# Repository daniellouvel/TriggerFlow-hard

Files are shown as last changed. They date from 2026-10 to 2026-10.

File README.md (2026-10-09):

# TriggerFlow — Architecture matérielle

> **Branche `v2-wroom`** : version 2, la DevKit est remplacée par le module ESP32-S3-WROOM-1-N16R8 soudé sur la carte (mêmes GPIO, firmware inchangé). Voir [docs/mcu-v2-wroom.md](docs/mcu-v2-wroom.md). La v1 (DevKit) est sur `main` et l'étiquette `v1.0`.

Boîtier de déclenchement généraliste pour photographie haute vitesse : détection multi-capteurs, moteur de règles programmable, pilotage de sorties variées (flash, électrovannes, appareil photo, servo, relais) et d'appareils secteur via des prises Wi-Fi.

Contrôlable par **USB (PC)** et **Wi-Fi/BLE (application mobile)**.

Statut (05/10/2026) : **schéma complet et validé** dans EasyEDA (Blocs 1, 2, 3, 5, 5b, 8, 10, 12 servo, 13 relais et feuille ESP32) : netlist vérifiée net par net, ERC 0 erreur / 0 avertissement ; référence : `netlist/Netlist_Schematic1_2026-10-05.tel`. Moteur pas à pas, PWM lumière/servo et relais ×3 supprimés (prises Wi-Fi). Module capteur universel conçu (8 variantes). Implantation PCB v4 (175 × 125 mm, 4 couches) recalée sur la netlist de référence. Firmware non commencé.

---

## 1. Plateforme

- **MCU** : module ESP32-S3-WROOM-1-**N16R8** soudé sur la carte (16 Mo flash Quad, 8 Mo PSRAM Octal) ; en v1, le même module sur une DevKitC-1
- **Cœurs** : dual-core Xtensa LX7, 240 MHz
- **Connectivité native** : Wi-Fi 2.4 GHz, Bluetooth LE, USB natif (device)
- v2 : **1 port USB-C** sur l'USB natif (GPIO 19/20) → programmation (USB-Serial/JTAG) et **contrôle PC** ; console série UART0 (GPIO 43/44) sur pastilles de test la barrette U103 (GND, TX, RX)
- v1 : la DevKit avait 2 ports USB-C (pont série et USB natif)

## 2. Cahier des charges fonctionnel

| Paramètre | Valeur retenue |
|---|---|
| Canaux d'entrée (capteurs) | 6, génériques et reconfigurables (gain + seuil logiciels) |
| Types de capteurs supportés | Son, laser/optique, piézo, contact sec — adaptables via un front-end universel |
| Utilisation des entrées | Rarement simultanées ; les 6 canaux existent surtout pour la flexibilité de branchement, pas pour du traitement massivement parallèle en continu |
| Logique inter-canaux | Moteur de règles programmable (ET / OU / conditions avancées), pas de simple mapping 1:1 figé |
| Précision de déclenchement | ±10 µs ou mieux |
| Plage de délai programmable | De la µs à plusieurs secondes, résolution constante |
| Alimentation | Secteur (pas de contrainte de consommation) |
| Pilotage | USB (PC), Wi-Fi (page web servie par le boîtier et/ou app mobile), Bluetooth LE (contrôle de proximité / mode secours) |
| Affichage local | Aucun (tout passe par l'app / le logiciel PC) |

## 3. Sorties

| Sortie | Quantité | Indépendance | Étage de puissance |
|---|---|---|---|
| Flash (pulse simple) | 4 | Délai indépendant par canal | Opto HCPL-063L + inverseur 74LVC2G04 + 2N7002, côté isolé (VISO) |
| Déclenchement appareil photo | 1 prise, **focus + shutter séparés** (2 contacts) | Timing indépendant | Idem flash (isolé) |
| Électrovanne | 6 | Durée de pulse indépendante par canal | AO3400A + diode de roue libre SS14, PTC 1,1 A |
| Servo | 1 | Non critique (LEDC 50 Hz) | Rail 6 V / 3 A dédié (LM2596S-ADJ depuis le 12 V, coupable), signal par buffer 74AHCT1G125 5 V |
| Relais (contact sec) | 1 | Non critique (MCP23017) | HF32F/012-ZS3, 1RT 3 A / 30 V DC, basse tension uniquement |
| **Prises Wi-Fi (secteur)** | illimité | Non critique (50–500 ms) | Prises connectées commandées en local (HTTP/MQTT) — voir section 3.1 |

**Total sur la carte : 14 sorties** (4 flash + 2 caméra + 6 vannes + servo + relais). Supprimés : moteur pas à pas (Bloc 4), PWM lumière/servo (Bloc 7), relais ×3 sur RJ45 (Bloc 6). Une **lumière 12 V dimmable** se branche sur une sortie vanne libre (même étage MOSFET, PWM ≈ 20 kHz par le firmware, 1,1 A max) : rien à ajouter côté matériel.

### 3.1 Sorties Wi-Fi (remplacent les relais)

Les appareils secteur sans contrainte de timing (éclairage, petit compresseur, ventilateur, pompe…) sont pilotés par des **prises connectées Wi-Fi** commandées par l'ESP32 sur **son propre réseau** (point d'accès SoftAP avec DHCP : sans box, utilisable partout) :
- prises recommandées : Shelly Plug S / Shelly 1PM, ou prises Tuya reflashées Tasmota / ESPHome (API locale HTTP ou MQTT, sans cloud) ; **≥ 10 A pour le compresseur** (appel de courant au démarrage) ;
- aucun 230 V dans le boîtier (sécurité, pas de certification secteur à porter) ; nombre de sorties non limité ;
- latence 50–500 ms et variable : réservé au non critique. Les commandes sont envoyées **avant ou après** une séquence de déclenchement, jamais pendant (l'activité Wi-Fi ajoute de la gigue aux interruptions) ;
Pour un contact sec basse tension : la **sortie relais** de la carte (Bloc 13), ou un module relais 12 V sur une sortie vanne libre ; pour une charge 12 V DC (ruban LED, ventilateur, pompe) : directement sur une sortie vanne (12 V, 1,1 A, PWM possible, non isolée).
Détails : [docs/sorties-wifi.md](docs/sorties-wifi.md).

## 4. Classification des signaux : natif vs I2C/SPI

Principe directeur de l'architecture GPIO : **seul ce qui a une exigence de timing en µs reste en GPIO natif avec ISR/timer dédié** ; tout le reste (configuration, signaux lents) passe par un bus série (I2C/SPI) pour économiser les broches.

### 4.1 GPIO natifs (chemin critique) — affectation validée

v2 : module **ESP32-S3-WROOM-1-N16R8** soudé (U101), **GPIO réaffectés pour le placement** (TLV_OUT inchangés ; SPI 17/18, I2C SDA 12 / SCL 11, LDAC 10, servo 48, vannes 2, 1, 47, 21, 14, 13, shutter 38, flash 39-42). Table complète et `#define` du firmware v2 dans [docs/mcu-v2-wroom.md](docs/mcu-v2-wroom.md). Le tableau ci-dessous est celui de la **v1** (DevKit).

| Signal | GPIO (v1) | Broche DevKit v1 (symbole U101) |
|---|---|---|
| TLV_OUT_1 … TLV_OUT_6 (entrées, ISR) | 4, 5, 6, 7, 15, 16 | 4 à 9 |
| FLASH_1_CMD, FLASH_2_CMD, FLASH_3_CMD, FLASH_4_CMD | 17, 21, 39, 41 | 10, 27, 36, 38 |
| SHUTTER_CMD | 42 | 39 |
| GPIO_VALVE_1 … GPIO_VALVE_6 | 1, 2, 10, 38, 48, 47 | 41, 40, 16, 35, 29, 28 |
| SERVO_PWM (LEDC 50 Hz) | 13 | 19 |
| libre (réserve) | 14 | 20 |
| I2C_SDA / I2C_SCL | 8 / 9 | 12 / 15 |
| SPI_MOSI / SPI_SCK (PGA) | 11 / 12 | 17 / 18 |
| DAC2_LDAC (programmation adresse du 2e MCP4728) | 18 | 11 |
| **Total** | **24 utilisés** | GPIO14 et GPIO40 libres |

Alimentation v2 : 5V_MCU par deux diodes SS14 (D101 depuis +5V, D102 depuis le VBUS de l'USB) → U104 AMS1117-3.3 → **3V3_MCU**, rail dédié au module, séparé du +3V3 de l'électronique (U116).

### 4.2 Périphériques I2C (non critique en timing)

```
ESP32-S3 (I2C : v1 GPIO 8 = SDA, GPIO 9 = SCL ; v2 GPIO 12 = SDA, GPIO 11 = SCL ; pull-ups 4,7 kΩ R114/R115 vers +3V3, sur la feuille MCU)
   │
   ├── MCP23017 (0x20) — expandeur 16 E/S
   │      ├── GPA0-5 : CS_1 … CS_6 des 6 MCP6S91
   │      ├── GPA6   : FOCUS_CMD
   │      ├── GPB2   : RELAY_CMD (sortie relais)
   │      ├── GPB3   : SERVO_OFF (coupure du rail servo)
   │      ├── GPB5   : LED de statut (déportée, CN111)
   │      └── GPA7, GPB0-1, GPB4, GPB6-7 : réserve
   ├── MCP4728 #1 (0x60) — seuils THR_1 … THR_4 (LDAC à GND)
   ├── MCP4728 #2 (0x61, reprogrammée via LDAC = GPIO18) — THR_5, THR_6
   └── ADS7828 (0x48) — lecture des 6 lignes ID (ID_ADC_1 … 6)
```

### 4.3 Chaîne d'entrée universelle (×6, identiques) — v3

```
RJ45 (4-5 signal, 1-2 alim 5 V via PTC 200 mA, 7-8 ID, 3-6 GND)
   → TVS PESD5V0S1BB + tirage 4,7 kΩ optionnel (JP) + 1 MΩ vers GND
   → 2,2 kΩ série + écrêteur BAT54S + 100 pF
   → MCP6S91 — PGA SPI (gain ×1 à ×32), VREF = GND
   → TLV3501 — comparateur, hystérésis ≈ 48 mV (10 k / 680 k), seuil THR_n par DAC (filtré 1 k / 100 nF)
   → GPIO natif ESP32-S3 (interruption)
Ligne ID : tirage 10 kΩ vers +3V3, TVS, 1 kΩ série → ADS7828
```

- Signal attendu : **continu, unipolaire 0–3,3 V, ≈ 0 V au repos** (le couplage AC et la polarisation Vcc/2 de la v2 sont supprimés ; la mise en forme est faite dans le module capteur).
- **TLV3501** : ~4,5 ns, non limitant face à la latence ISR (~1-3 µs). **MCP6S91** : un PGA par entrée.

## 5. Architecture logicielle (cœurs / tâches)

```
CORE 0 (PRO_CPU)                          CORE 1 (APP_CPU) — dédié chemin critique
─────────────────────                     ──────────────────────────────────────
• Pile Wi-Fi/BLE                          • ISR GPIO ×6 (entrées capteurs), IRAM_ATTR
• Serveur de contrôle USB (CDC)           • esp_timer (dispatch ISR) pour toutes les sorties,
• Tâche I2C → DAC / expandeur / PGA         délais indépendants par canal
• Tâche NVS / logging                     • Priorité maximale, xTaskCreatePinnedToCore(...,1)
• Moteur de règles (évaluation non-µs)    • Aucune tâche Wi-Fi/BLE épinglée ici
```

**Point clé** : l'ESP32-S3 ne dispose que de 4 `gptimer` matériels, insuffisant pour 13 sorties potentiellement indépendantes et simultanées. Solution retenue : le service **`esp_timer`** (timers logiciels haute résolution µs, dispatch en mode ISR pour éviter la latence de changement de contexte FreeRTOS), qui gère un nombre illimité d'alarmes virtuelles sur un seul timer matériel sous-jacent.

## 6. Mémoire

| Ressource | Usage prévu |
|---|---|
| Flash 16 Mo | NVS (presets seuils/délais/règles), OTA double-slot, firmware, LittleFS (logs horodatés) |
| PSRAM 8 Mo Octal | Non-critique uniquement : buffers réseau, historique de déclenchements — **jamais** de code/donnée du chemin temps réel (latence d'accès variable) |

## 7. Contraintes GPIO de la carte N16R8 (rappel)

- **GPIO 26-37** : indisponibles (bus interne flash/PSRAM Octal — non sortis sur le module WROOM)
- **GPIO 33-34** : non sortis sur le module, à ne jamais adresser même en logiciel
- **GPIO 0, 3, 45, 46** : broches de strapping — utilisables prioritairement en sortie, prudence en entrée
- **GPIO 19-20** : réservées USB natif (contrôle PC)
- **GPIO 43-44** : réservées USB-UART (programmation/debug)
- Tout code du chemin critique (ISR, callbacks `esp_timer`) doit être marqué `IRAM_ATTR` pour éviter les cache-miss flash

## 8. Comparatif marché (état à date de rédaction)

| Aspect | Marché (StopShot Studio = référence haut de gamme) | TriggerFlow |
|---|---|---|
| Sorties totales | 12 max | 14 + prises Wi-Fi |
| Sorties flash indépendantes natives | 1 (accessoire externe pour plus) | 4 |
| Axe motorisé intégré | Aucun produit identifié n'en propose | Servo dédié (rail 6 V), pas d'axe pas à pas |
| Entrées reconfigurables | Fixes ou peu nombreuses | 6, gain/seuil logiciels |
| Contrôle sans fil | Oui chez MIOPS, non chez StopShot Studio (USB uniquement) | Oui (Wi-Fi/BLE) + USB |

### Fonctionnalités confirmées au cahier des charges (logiciel, aucun impact matériel)
- **Mode "sorties désactivées"** : verrou logiciel global (armé/désarmé) évalué par le moteur de règles avant tout déclenchement. Décision actée : **désarmement logiciel uniquement via app/PC**, pas d'interrupteur physique de sécurité en façade.
- **Outils de mesure** : vitesse de projectile (calculée à partir des timestamps de deux entrées capteur sur une même trajectoire) et latence de déclenchement de l'appareil photo. Repose entièrement sur l'infrastructure de timestamping déjà prévue par les ISR — aucun composant supplémentaire.

### Point encore ouvert
- Fallback de contrôle local minimal (LED de statut) en cas de perte Wi-Fi/BLE sur le terrain — non tranché

## 9. Performance et budget de latence

### 9.1 Chaîne de latence (hors propagation physique du signal capteur)

| Étage | Latence typique |
|---|---|
| TLV3501 (comparateur) | ~5-7 ns |
| MCP6S91 (PGA, bande passante 1-18 MHz selon gain) | ~350 ns à gain faible ; **non vérifié à gain ×32** (la bande passante chute avec le gain — pourrait approcher 1-2 µs, à confirmer au datasheet avant routage, surtout sur les canaux à fort gain type micro) |
| Interruption GPIO ESP32-S3 | ~1-3 µs |
| Callback `esp_timer` (dispatch ISR) | voir 9.2 |
| Sortie GPIO physique | ~1-3 µs |
| **Total chemin électronique** | **~2 à 10 µs**, conforme à l'objectif ±10 µs |

### 9.2 Contrainte technique vérifiée sur `esp_timer`

- Mode `ESP_TIMER_ISR` : plancher d'environ **20 µs** pour un timer one-shot (tout délai demandé en dessous est en pratique dispatché à ~20 µs).
- Timer périodique : période minimale d'environ **50 µs** (inadapté aux signaux périodiques rapides : on utilise LEDC/RMT).

**Décisions d'architecture qui en découlent :**
- **Signaux périodiques (servo 50 Hz, PWM des vannes / lumière)** : sur LEDC (périphérique matériel dédié), jamais sur `esp_timer`.
- **Délais de déclenchement (flash/vannes/shutter)** : architecture hybride — délai < ~20 µs routé vers l'un des 4 `gptimer` matériels natifs (précision garantie, sans plancher), délai ≥ ~20 µs routé vers `esp_timer` (nombre de canaux illimité). Choix fait dynamiquement par le firmware selon le délai demandé.

### 9.3 Point de validation en phase de test (non tranché sur plan)
- Impact réel du trafic Wi-Fi/BLE sur le jitter des ISR du Core 1 : pas de chiffre garanti par la documentation Espressif, dépend du trafic au moment T. Mitigé par l'épinglage Core 1 dédié et le réglage du niveau de priorité d'interruption d'`esp_timer` (1 à 3). **À mesurer à l'oscilloscope sur le premier prototype**, jitter entrée→sortie avec Wi-Fi actif vs coupé.

### 9.4 Exemple d'application — impact du choix de capteur sur la précision finale
Cas : carabine à air comprimé, plomb à ~250 m/s.
- **Capteur son** : le délai de propagation acoustique (343 m/s) domine très largement le budget — à 30 cm du canon, le plomb a déjà parcouru ~22 cm avant déclenchement, contre <1 mm imputable à l'électronique. Le placement du capteur compte infiniment plus que la précision électronique pour ce cas d'usage.
- **Capteur laser (photodiode PIN + transimpédance)** : élimine le délai de propagation, ramène le déplacement du plomb pendant le délai de déclenchement à ~0,5-1,25 mm (inférieur au diamètre du plomb). Le facteur limitant devient alors la **durée d'éclair du flash** lui-même, pas l'électronique de déclenchement.
- Conclusion générale : pour les capteurs son, privilégier les cas où la source sonore est proche du sujet photographié ; pour les projectiles très rapides, privilégier systématiquement une détection optique (laser/photodiode) plutôt qu'acoustique.

## 11. Connectique — RJ45 généralisé

Connecteurs **RJ45 blindés 10 broches HanXia HX-RJ45 90 5631-1x1 (LCSC C25168869)** pour toutes les liaisons faible courant ; vannes, servo, relais et alimentation sur connecteurs dédiés.

**11 connecteurs RJ45 au total** : 6 entrées capteur + 4 flash + 1 appareil photo (focus + shutter). Les RJ45 « contact sec » (Bloc 6) et PWM (Bloc 7) sont supprimés ; le servo (barrette 3 points) et le relais (bornier COM / NO / NC) ont leurs propres connecteurs.

### Brochage

| Broches | Entrées capteur (×6) | Flash (×4) | Appareil photo (×1) |
|---|---|---|---|
| 1-2 | V_SENS 5 V (PTC 200 mA) | non connectées | non connectées |
| 3 | GND | non connectée | **FOCUS** |
| 4 | Signal capteur | **FLASH_n** (drain 2N7002) | **SHUTTER** |
| 5 | Signal capteur | **VISO_GND** (retour) | VISO_GND (retour shutter) |
| 6 | GND | non connectée | VISO_GND (retour focus) |
| 7-8 | ID (code du capteur) | non connectées | non connectées |
| 9-10 (blindage) | GND | **non connectées** | **non connectées** |

- Sorties flash / appareil photo : chaque signal est dans la même paire que son retour ; **retour sur VISO_GND, jamais sur GND** ; blindage non connecté (sinon la façade métallique relierait VISO_GND à GND) ; câble UTP conseillé.
- Polarité côté flash : broche 4 = + de la synchro, broche 5 = −. TVS SMF24A sur chaque sortie : flashs jusqu'à 24 V de synchro (au-delà : adaptateur type Safe-Sync).

### Auto-détection du type de capteur

Résistance de codage entre ID (7-8) et la masse dans le module capteur, tirage 10 kΩ vers 3,3 V sur la carte, lecture par l'ADS7828 (référence interne 2,5 V). **12 codes fiables** dans le pire cas (tolérances 1 %, rail ±3 %, décalage de masse 40 mV) :

| Code | R_ID | Code | R_ID |
|---|---|---|---|
| 1 | 0 Ω | 7 | 3 kΩ |
| 2 | 220 Ω | 8 | 4,3 kΩ |
| 3 | 510 Ω | 9 | 6,2 kΩ |
| 4 | 910 Ω | 10 | 8,2 kΩ |
| 5 | 1,5 kΩ | 11 | 12 kΩ |
| 6 | 2,2 kΩ | 12 | 18 kΩ |

Ligne ouverte (lecture pleine échelle) = aucun capteur. Affectation des codes aux variantes du module capteur universel : voir BOM-netlist.md, Bloc 9.

## 13. Connecteurs vannes, servo, relais et alimentation

### Connecteurs puissance (hors RJ45) — famille GX12

Choix retenu : **connecteurs circulaires aviation GX12** pour les vannes et l'alimentation, en remplacement du JST-XH envisagé initialement — plus robustes pour un usage en façade manipulé sur le terrain (verrouillage à vis, tenue ~3-5A par broche selon variante, bien au-dessus du besoin), alors que le JST-XH est plutôt pensé pour du câblage interne de carte.

| Élément | Connecteur | Notes |
|---|---|---|
| Électrovanne (×6) | GX12 2 broches | +/- alimentation vanne |
| Servo | bornier 3 points 5,08 mm KF128 (C474953) | 1 = GND, 2 = V_SERVO 6 V, 3 = signal (rallonge servo à câbler) |
| Relais | bornier 3 points 5,08 mm KF128 (C474953) | COM / NO / NC, basse tension uniquement |
| Alimentation générale (entrée DC) | GX12 ou GX16 selon courant total | Voir section alimentation ci-dessous |

**Périmètre délibérément limité** : le GX12 reste réservé aux connecteurs de puissance. Les 11 connecteurs signal (entrées capteur + sorties flash / appareil photo) restent en **RJ45** (voir section 11) — meilleur compromis coût/disponibilité de câbles préfabriqués/qualité de signal (paires torsadées) pour du faible courant, l'étanchéité renforcée du GX12 n'étant pas jugée nécessaire pour ces liaisons dans l'usage prévu. Bénéfice supplémentaire : les deux familles de connecteurs sont physiquement incompatibles entre elles, ce qui empêche tout branchement erroné (vanne sur un port capteur, par exemple).

### Architecture d'alimentation (Bloc 5 et 5b, validés)

Alimentation externe : **bloc secteur 12 V, 5 A minimum (60 W)**, pas de 230 V dans le boîtier.

```
Bloc secteur 12 V → J112 → F112 (6,3 A T) → Q112 AO4407A (anti-inversion) → +12V
                                                  D112 SMBJ15A (TVS)        │
      ┌───────────────────────────────────────────────────────────────────┤
      ▼                                                                    ▼
  vannes (F91-96), relais (K131), U131 LM2596S-ADJ          U115 LM2596S-5.0 → +5V (3 A)
  → V_SERVO 6 V / 3 A (coupable, servo)                     ├→ module ESP32 (D101 → U104 → 3V3_MCU), capteurs (F11-61), buffer servo
                                                             ├→ U116 AMS1117-3.3 → +3V3 (électronique)
                                                             └→ U117 B0505S-1WR3 (isolé) → U118 AMS1117-3.3 → VISO_3V3 / VISO_GND
                                                                                         (sorties flash / appareil photo)
```

- Le 3V3_MCU (U104) n'alimente que le module ESP32 ; tout le reste est sur +3V3 (U116). L'USB (VBUS, D102) peut alimenter le module seul pour la programmation.
- Le côté isolé (VISO) n'a **aucun conducteur commun** avec GND : il protège l'ESP32 et les entrées analogiques des perturbations des flashs, évite les boucles de masse entre boîtier, appareil photo et flashs secteur.

## 14. Synoptique général du montage

Plutôt qu'un seul diagramme complet (illisible avec autant de blocs), voici la même architecture découpée en 4 schémas simples, chacun centré sur une seule idée.

### 14.1 Vue d'ensemble

```
   Alimentation 12V DC (bloc secteur externe)
                  │
                  ▼
   ┌─────────────────────────────────┐
   │   ESP32-S3-WROOM-1 (N16R8)       │
   │                                  │
   │   Core 0 : réseau / contrôle     │
   │   Core 1 : temps réel (critique) │
   └────────────┬─────────────┬───────┘
                │             │
                ▼             ▼
      6 entrées capteurs   14 sorties + prises Wi-Fi
      (connecteurs RJ45)   (RJ45 pour le signal,
                            GX12 pour la puissance)
```

### 14.2 Chaîne d'une entrée capteur (répétée ×6, identique)

```
Capteur          Ampli à gain        Comparateur         ESP32-S3
(RJ45)     →     programmable   →    + seuil réglable →  (interruption,
                  MCP6S91 (SPI)       TLV3501              Core 1)
                                      + DAC (I2C)
```

### 14.3 Qui parle à qui sur les bus de configuration

```
                         ┌── MCP4728 ×2  → seuils des 6 comparateurs
ESP32-S3 ── I2C ──┼── MCP23017    → focus caméra, CS des PGA, relais,
                         │              coupure servo, LED de statut
                         └── ADS78xx    → lecture ID des capteurs (auto-détection)

ESP32-S3 ── SPI ──── 6× MCP6S91  → réglage du gain de chaque entrée
```

*(Ces bus ne portent que de la configuration — rien ne transite dessus pendant un déclenchement, donc aucun impact sur la précision temporelle.)*

### 14.4 Les sorties, groupées par nature

```
Core 1 (temps réel, GPIO natif)          Expandeur I2C (non critique)
─────────────────────────────            ────────────────────────────
4× Flash            (RJ45, isolé)         1× Relais (bornier, contact sec)
1× Caméra focus+shutter (RJ45, isolé)    Prises Wi-Fi secteur (réseau de l'ESP32)
6× Électrovanne      (GX12)
1× Servo             (rail 6 V dédié, LEDC 50 Hz)
```

**Ce qu'il faut retenir de ces 4 schémas** :
- Le chemin capteur → déclenchement (14.2 + 14.4 colonne de gauche) est le seul qui doit rester ultra-rapide — tout le reste (14.3) ne fait que régler des paramètres, jamais pendant une prise.
- Deux familles de connecteurs bien séparées : RJ45 pour tout ce qui est signal, GX12 pour tout ce qui est puissance — impossible de les confondre en branchant.

## 15. Ouvert / non tranché

- **Schéma** : terminé (référence du 05/10). Points restants : R133 3,9 kΩ (C23018 en rupture, secours 39 k / 10 k), D101 = SS14 C2480 à confirmer (en v2, plus de barrettes : le module est soudé).
- **v2 (module WROOM)** : saisie de la feuille MCU dans la copie EasyEDA « TriggerFlow v2 WROOM » et vérification de sa netlist ; orientation réelle de l'empreinte du module (broche 1, antenne).
- **Vérifications** : empreintes réelles (RJ45, module, USB-C, relais) avant de figer le placement.
- **PCB** (voir `pcb/` et `docs/pcb-checklist.md`) : cotes réelles du RJ45 HanXia C25168869, orientation broche 1 des empreintes, boîtier plastique ou métallique (métallique → WROOM-1U à antenne externe, C3013946, à décider avant routage), raccordement des trous de fixation à la masse.
- **Connecteur vanne** : HX25003-2A droit ou coudé ; GX12 de façade (2 ou 4 broches).
- **Bande passante MCP6S91 à gain ×32** à confirmer à la datasheet.
- **Limite connue** : au-delà de 4 sorties simultanées à délai < 20 µs, plancher `esp_timer` (~20 µs).
- **Module capteur universel** : saisie EasyEDA et PCB (schéma KiCad dans `kicad/module_capteur/`).
- **Firmware** : moteur de règles, protocole USB CDC / web / BLE, Wi-Fi en point d'accès + pilotage des prises, mode « lumière » des sorties vannes, servo (coupure SERVO_OFF au démarrage), lecture ID et presets par variante, reprogrammation d'adresse du 2e MCP4728.
- **Mécanique** : boîtier, façade (11 RJ45, 6 GX12, entrée 12 V, servo, relais, 1 USB-C en v2).

## 16. Implantation PCB

Carte **175 × 125 mm, 4 couches** (JLC 1,6 mm, 1 oz) : couche 1 composants et signaux courts, couche 2 **GND plein** (îlot VISO séparé), couche 3 plages d'alimentation (+12V au quart droit, +3V3 au centre, +5V en bandes le long des bords), couche 4 signaux longs.

Zones : sorties isolées au bord arrière gauche (barrière d'isolation à y = 40 mm, seuls les 3 HCPL-063L et le B0505S la traversent, ≥ 3 mm sans cuivre sur toutes les couches) ; module ESP32 au bord gauche avec l'antenne au bord (zone sans cuivre de 7 mm, plus de fente en v2) et l'USB-C juste en dessous ; rail 3V3_MCU dédié ; colonne de droite : servo, relais et entrée 12 V à l'arrière, vannes au milieu, 12 V → 5 V et +3V3 dans le coin avant droit ; bus I2C au centre ; couloir de bus de 8 mm en couche 4 ; 6 entrées capteur au bord avant (bandes de 18 mm). Placement de 305 composants (v2) vérifié par script (chevauchements, zone antenne, barrière, trous M3).

Détails, fichier de positions et scripts : [pcb/README.md](pcb/README.md) ; checklist : [docs/pcb-checklist.md](docs/pcb-checklist.md).

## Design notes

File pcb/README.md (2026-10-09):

# Implantation PCB TriggerFlow (v4, 04/10/2026)

> Branche **v2-wroom** : placement avec le module WROOM-1 (304 composants). Netlist d'entrée `netlist_v2_wroom.json` = **export EasyEDA du 10/10** (`netlist_v2_easyeda_2026-10-10.tel`), numérotation EasyEDA (U101 = module, U115 = LM2596 5 V, U131 = LM2596 servo… correspondance complète dans `docs/mcu-v2-wroom.md`). `mcu_v2.py` (ancienne netlist construite depuis la v1) n'écrit plus que `netlist_v2_ancienne_numerotation.json`. Zoom de la zone module : `zoom_mcu_v2.png`.

Placement des **287 composants** en v1, **305** en v2 (export EasyEDA de référence du 05/10, servo et relais compris, sans moteur ni PWM) sur une carte **175 × 125 mm, 4 couches**. Repère : origine au coin arrière gauche, x vers la droite, y vers l'avant. Tailles = encombrements estimés, à recaler sur les vraies empreintes.

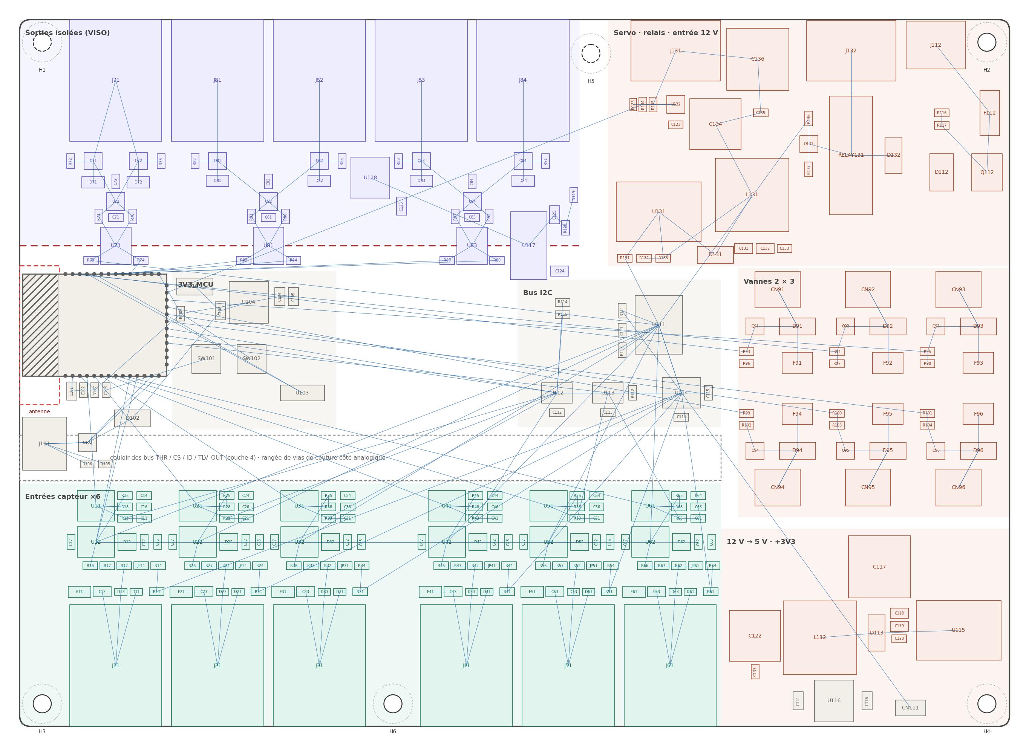
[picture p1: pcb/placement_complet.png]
Placement complet


| Fichier | Rôle |
|---|---|
| `placement_TriggerFlow.csv` | référence, valeur, empreinte, X, Y, rotation, face, bloc (séparateur `;`) + trous M3 |
| `place.py` | positions de chaque composant |
| `check.py` | contrôle : chevauchements, bords, zone antenne, barrière d'isolation, trous M3 |
| `render.py` | dessin du placement et du chevelu (hors plans GND / alimentations) + 3 zooms |
| `export_csv.py` | régénère le CSV |
| `netlist_2026-10-05.json` | netlist de référence (export EasyEDA du 05/10) |

Usage : `python3 check.py && python3 render.py && python3 export_csv.py` (dépendance : matplotlib).

## Empilement (JLC 4 couches, JLC04161H-7628, 1,6 mm, cuivre 1 oz)

| Couche | Contenu |
|---|---|
| 1 (dessus) | composants et signaux, dont les signaux analogiques courts |
| 2 | **GND plein**, sans aucune piste (sauf l'îlot VISO_GND séparé) ; jamais coupé sous les bandes analogiques ni sous l'I2C |
| 3 | plages d'alimentation : **+12V** limité au quart droit (alim, servo, relais, vannes) ; **+3V3** au centre et à l'avant (à partir de x = 52 au-dessus du couloir de bus) ; **3V3_MCU** sous le module et son régulateur (x 9–50, y 45,5–72,5) ; **+5V** en bandes étroites (avant sous les RJ45, bande verticale vers U116, tronçon sous la barrière prolongé jusqu'à D101) ; **VISO_3V3** dans l'îlot |
| 4 (dessous) | signaux longs : SPI, CS, I2C, SERVO_PWM, commandes des vannes, TLV_OUT |

Une piste de couche 4 prend son retour dans la couche 3 (noyau épais entre L2 et L3) : elle ne traverse jamais une frontière entre plages de la couche 3 (sinon condensateur de couture 100 nF ou passage en couche 1). Une piste qui doit entrer dans la zone 12 V change donc de couche avant la frontière (ex. SERVO_PWM : couche 4 puis via et couche 1 jusqu'à U132). Une piste qui traverse une bande analogique passe en couche 4, à angle droit.

## Zones (bord arrière en haut)

| Zone | x (mm) | y (mm) | Contenu |
|---|---|---|---|
| Sorties isolées (VISO) | 0–99 | 0–40 | J71, J81-J84 au bord arrière ; TVS, 2N7002, 74LVC2G04, HCPL-063L |
| Barrière d'isolation | 0–99 | y = 40 | seuls U71, U81, U83, U117 à cheval ; ≥ 3 mm sans cuivre sur les 4 couches |
| Servo, relais, entrée 12 V | 104–175 | 0–43,5 | bord arrière : J131 (servo) + C136, J132 (relais), J112 (12 V) ; RELAY131, Q131, D132 ; U131 (languette à gauche) + L131, C134, D131 ; F112, Q112, D112 au bord droit |
| Module ESP32-S3-WROOM-1 (v2) | 0,5–26 | 45–63 (U101 tourné de 90°) | antenne au bord gauche (x 0,5–6,8) ; broches 1-14 vers l'avant |
| USB-C J101 + U102 | 0,5–16 | 70–80 | USB natif, protection USBLC6, CC 5,1 k |
| 3V3_MCU, RESET, BOOT | 27–56 | 44,5–72,5 | U104 AMS1117, D101 / D102, SW101 / SW102 |
| Zone antenne | 0–7 | 43,5–68 | sans cuivre sur les 4 couches (v2 : plus de fente) |
| Bus I2C | 88–124 | 46–72 | U111 MCP23017, U112/U113 MCP4728, U114 ADS7828 |
| Couloir de bus | 0–124 | 73,5–81,5 | THR / CS / ID / TLV_OUT en couche 4 ; rangée de vias de couture côté analogique |
| Vannes 2 × 3 | 127–175 | 44–88 | CN91-CN93 (y ≈ 48) et CN94-CN96 (y ≈ 83) vers l'extérieur, rail +12V au milieu ; D9n entre CN9n et Q9n |
| Entrées capteur ×6 | 0–124 | 82–125 | J11-J61 au bord avant (x = 17, 35, 53, 79, 97, 115), bande de 18 mm par voie |
| 12 V → 5 V, +3V3, LED | 124–175 | 90–125 | U115 tourné (broches à gauche, languette au bord droit), C117 au-dessus de l'entrée, C118-C120 et D113 collés aux broches, L112 et C122 à gauche ; U116, C121, C116, CN111 au bord avant |

**Trous M3** : H1 (4, 4) et H5 (101, 6) côté VISO en **NPTH** (jamais reliés à la masse) ; H2 (171, 4), H3 (4, 121), H4 (171, 121), H6 (66, 121) en GND ; H7 supprimé (sa pastille coupait la bande +5V d'Inner2). Exclusion de 7 mm de diamètre autour de chaque trou.

## Règles clés appliquées au placement

- Chaque voie d'entrée suit le trajet du signal : RJ45 → TVS/PTC → R16 / BAT54S / C12 → MCP6S91 → TLV3501 → TLV_OUT vers la rangée J1 de l'ESP32. TLV_OUT (fronts de 4,5 ns) ne longe jamais l'entrée CLAMP du PGA ; filtre THR (R13/C11) collé à la broche 2 du TLV3501.
- Découplages à ≤ 2 mm de leur broche, via GND juste à côté.
- Boucles de découpage courtes (C117 → U115 → D113 ; C131/C132 → U131 → D131), ≈ 15 vias thermiques sous les languettes de U115 et U131 (deux plans internes à traverser), électrolytiques à ≥ 5 mm des languettes, L112 et L131 à 90° et ≥ 10 mm.
- Pistes +12V, VALVE_PWR, VALVE_SW ≥ 2 mm ou plages ; ≥ 2 vias par source de MOSFET (Q91-Q96, Q131) vers la couche 2.
- Isolation : aucune piste, via ou plan ne traverse la barrière hors U71/U81/U83/U117 ; bande sans cuivre sous U117 ; blindages J71/J81-J84 non connectés ; ≥ 3 mm entre la zone relais (GND) et l'îlot VISO.
- Tout sur la face du dessus (assemblage JLC simple face) ; 3 fiducials ; ≥ 0,5 mm entre cuivre et bord.
- Points de test : +12V, +5V, +3V3, 3V3_MCU, VISO_3V3, V_SERVO, GND, VISO_GND, I2C_SDA/SCL, SPI_MOSI/SCK, TLV_OUT_1 à 6 ; console UART0 sur la barrette U103 (GND, TX, RX) (v2).
- Sérigraphie : V1 à V6 et + / − près de CN91-CN96 ; « BASSE TENSION, 30 V max, jamais de 230 V » près de J132 ; numéro de voie près de chaque RJ45 ; marquage de la zone isolée.

Checklist complète à cocher : [docs/pcb-checklist.md](../docs/pcb-checklist.md).

## Changements par rapport au plan de zones initial

- Couloir de bus de 8 mm (y 73,5–81,5) à la place de la bande de garde : les 24 liaisons THR, CS, ID et TLV_OUT y passent en couche 4. L'ESP32 remonte de 3 mm.
- U117 (B0505S) déplacé sous J84 : il était dans l'axe de l'antenne.
- U118 au centre de l'îlot isolé (alimente les trois optos répartis sur toute la largeur).
- Servo et relais repris avec les repères EasyEDA du 05/10 : J131 et J132 sont des borniers KF128 3P (15,8 × 10,7 mm) ; J131 recentré (x = 169,15), L131 décalé à x = 153, petits composants du servo replacés en colonne à x ≈ 162, C136 (470 µF) sous J131, RELAY131 descendu à y = 23,2, J132 à y = 5,7.

## Encore approximatif / à confirmer

- Empreinte exacte du RJ45 HanXia C25168869 (largeur supposée 16 mm, pas de 18 mm), dimensions du relais, orientation réelle de l'empreinte du module (broche 1, antenne).
- Rotation 0 = orientation par défaut de l'empreinte : vérifier la broche 1 sur la bibliothèque réelle.
- Dégagement autour des connecteurs de vannes de la 1re rangée ≈ 1,5 mm entre C136 et CN93 (5 mm visés) : à reprendre avec les vraies empreintes.
- Boîtier plastique ou métallique (métallique → module WROOM-1U-N16R8 C3013946 à antenne externe u.FL, à décider avant routage).
- Application dans EasyEDA Pro : saisie manuelle ou Claude Code + easyeda-copilot lisant le CSV (déplacer une empreinte sur le PCB ne casse pas les liaisons).

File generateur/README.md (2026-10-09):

# Générateur de feuilles KiCad (.kicad_sch v20260306)

Scripts Python qui produisent des feuilles KiCad propres, avec fils tirés sur les positions réelles des broches, puis vérifient la netlist par géométrie.

| Fichier | Rôle |
|---|---|
| `kicadgen.py` | moteur : symboles, fils, jonctions, étiquettes, zones, sérialisation |
| `kicad_net.py` | relit un .kicad_sch et calcule la netlist (`python3 kicad_net.py feuille.kicad_sch`) |
| `render.py` | aperçu PNG approximatif (`python3 render.py feuille.kicad_sch apercu.png [a3]`) |
| `libextract.py` | extrait et aplatit des symboles des bibliothèques KiCad standard (paquet Ubuntu `kicad-symbols`) |
| `src_*.kicad_sch` | bibliothèques de symboles embarquées utilisées par chaque feuille |
| `bloc5.py` / `build_bloc5.py` | Bloc 5 — alimentation |
| `bloc5b.py` / `build_bloc5b.py` | Bloc 5b — alimentation isolée |
| `capteur.py` / `build_capteur.py` | module capteur universel |
| `mkbuild.py` | construction générique d'une feuille autonome + symboles personnalisés |
| `servo.py`, `relais.py` / `build_sorties.py` | sortie servo (rail 6 V) et sortie relais |
| `mcu.py` / `build_mcu.py` | feuille MCU v2 : module ESP32-S3-WROOM-1 (nets lus dans `pcb/netlist_v2_wroom.json`) → `kicad/mcu_v2/`, variante EasyEDA `kicad/easyeda/mcu_wroom.kicad_sch` |

Usage : `python3 build_bloc5.py sortie/` ; variante EasyEDA (sans champs cachés) : `EASYEDA=1 python3 build_bloc5.py sortie/`.
Dépendances : `pip install sexpdata matplotlib`.
Non vérifié : ouverture dans KiCad 10 et ERC (à faire côté utilisateur).

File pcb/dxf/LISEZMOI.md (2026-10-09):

# DXF TriggerFlow pour EasyEDA Pro

Unité : mm. Origine DXF : coin AVANT gauche de la carte (Y vers l'arrière).
Le placement (`pcb/placement_TriggerFlow.csv`) a son origine au coin ARRIÈRE gauche, y vers l'avant :
Y_dxf = 125 − y_placement.

| Fichier | Contenu | Couche EasyEDA à choisir à l'import |
|---|---|---|
| TriggerFlow_1_contour.dxf | contour 175 × 125 mm (coins R2), trous H1 et H5 Ø 3,2 non métallisés (v2 : plus de fente, l'antenne du module est au bord gauche) | Contour de carte (Board Outline) |
| TriggerFlow_2_trous_GND.dxf | repères de H2, H3, H4, H6 (H7 supprimé) : perçage Ø 3,2, pastille Ø 6, dégagement Ø 7 | Document ; puis poser à chaque repère une pastille traversante Ø 3,2 / 6 mm reliée au net GND (ou un trou de fixation M3) |
| TriggerFlow_3_zones_interdites.dxf | v2 : zone antenne au bord (x 0–7) et barrière d'isolation (y 38,5–41,5) | Document ; puis tracer par-dessus des zones interdites (cuivre, toutes couches) |
| TriggerFlow_4_zones_document.dxf | zones du plan, barrière d'isolation, couloir de bus, rangée de vias de couture | Document (repères pour le routage) |
| TriggerFlow_5_couche3_plages.dxf | contours des plages de la couche 3 : VISO_3V3, +12V, +3V3, +5V et, en v2, 3V3_MCU | Document, ou Interne 2 comme guide ; puis créer les remplissages de cuivre par-dessus en leur donnant le bon net |

Ordre conseillé : 1 (contour) → 2 et 3 → 4 et 5 → mise à jour du PCB depuis le schéma → placement.
Après l'import, vérifier une cote connue (largeur 175 mm, H6 à 66 mm du bord gauche) avant de continuer.
v2 : aucune plage du fichier 5 ne passe sous l'antenne ; la zone interdite du fichier 3 protège quand même toutes les couches.

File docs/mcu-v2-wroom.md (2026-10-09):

# TriggerFlow v2 — Feuille MCU : module ESP32-S3-WROOM-1-N16R8

Branche `v2-wroom`. La v1 (DevKit sur barrettes) reste sur `main` et l'étiquette `v1.0`.

## Fichiers du schéma

- `kicad/mcu_v2/mcu_wroom.kicad_sch` : feuille KiCad (A4) générée par `generateur/build_mcu.py`, aperçu `kicad/mcu_v2/apercu.png`.
- `kicad/easyeda/mcu_wroom.kicad_sch` : même feuille sans champs cachés, à importer dans EasyEDA Pro (copie « TriggerFlow v2 WROOM »).
- Netlist de la feuille vérifiée par calcul contre `pcb/netlist_v2_wroom.json` : 37 nets (avec les tirages I2C R114 / R115), aucun écart (la languette de U104 n'est pas une broche séparée du symbole KiCad ; elle est reliée à VO dans l'empreinte). Non ouverte dans KiCad 10 ni dans EasyEDA : ERC à faire.
- Les signaux vers les autres feuilles sont des étiquettes de net (TLV_OUT_1…, SPI_SCK, I2C_SDA, GPIO_VALVE_1…, FLASH_1_CMD…), comme dans les feuilles servo et relais.

## Numérotation EasyEDA (10/10/2026)

Le schéma EasyEDA « TriggerFlow v2 WROOM » a été renuméroté par EasyEDA (deux fois le 10/10). C'est cette numérotation qui fait foi : `pcb/netlist_v2_wroom.json` est l'export EasyEDA le plus récent (`pcb/netlist_v2_easyeda_2026-10-10.tel`), et le placement, la BOM-netlist, le README et la checklist l'utilisent. Correspondance vérifiée net par net à chaque renumérotation (0 écart). La feuille KiCad générée (`kicad/mcu_v2/`) garde la numérotation d'origine.

Changements volontaires faits dans EasyEDA : canal du USBLC6 inversé (D+ sur les broches 1/6, D− sur 3/4, équivalent) avec les nets USB_C_DP / USB_C_DN côté connecteur ; pastilles de test remplacées par la barrette U103 (1 GND, 2 TXD0, 3 RXD0) ; étiquettes V5_CAPT_1..6 entre PTC et RJ45 ; C87 (1 µF sur IO0) supprimé.

Les références des blocs 1 à 3 (entrées, sorties isolées, vannes) n'ont pas changé.

| Référence d'origine (docs du 06/10) | Numérotation actuelle |
|---|---|
| C101 | C111 |
| C102 | C112 |
| C103 | C113 |
| C104 | C114 |
| C105 | C115 |
| C111 | C116 |
| C112 | C117 |
| C113 | C118 |
| C114 | C119 |
| C115 | C120 |
| C116 | C121 |
| C117 | C122 |
| C118 | C137 |
| C119 | C124 |
| C120 | C125 |
| C121 | C126 |
| C122 | C131 |
| C123 | C132 |
| C124 | C133 |
| C125 | C134 |
| C126 | C135 |
| C127 | C136 |
| C128 | C123 |
| C141 | C103 |
| C142 | C101 |
| C143 | C102 |
| C144 | C104 |
| C145 | C105 |
| C146 | C106 |
| CN101 | CN111 |
| D101 | D101 |
| D111 | D112 |
| D112 | D113 |
| D121 | D131 |
| D122 | D132 |
| D123 | D133 |
| D141 | D102 |
| F111 | F112 |
| J111 | J112 |
| J121 | J131 |
| J122 | J132 |
| J141 | J101 |
| L111 | L112 |
| L121 | L131 |
| Q111 | Q112 |
| Q121 | Q131 |
| R105 | R111 |
| R106 | R112 |
| R107 | R113 |
| R108 | R114 |
| R109 | R115 |
| R111 | R116 |
| R112 | R117 |
| R113 | R118 |
| R114 | R119 |
| R121 | R131 |
| R122 | R132 |
| R123 | R133 |
| R124 | R134 |
| R125 | R135 |
| R126 | R136 |
| R127 | R137 |
| R141 | R107 |
| R142 | R108 |
| R143 | R106 |
| R144 | R105 |
| RELAY121 | RELAY131 |
| SW141 | SW101 |
| SW142 | SW102 |
| U101 | U111 |
| U102 | U112 |
| U103 | U113 |
| U104 | U114 |
| U105 | U101 |
| U111 | U115 |
| U112 | U116 |
| U113 | U117 |
| U114 | U118 |
| U121 | U131 |
| U122 | U132 |
| U141 | U104 |
| U142 | U102 |

## Principe

La DevKit est remplacée par le module qu'elle portait, **ESP32-S3-WROOM-1-N16R8**, soudé directement sur la carte. Chaque signal garde **le même GPIO** qu'en v1 : le firmware ne change pas. Seuls les numéros de broches du composant U101 changent.

Ce que la DevKit fournissait et qu'il faut maintenant ajouter : le 3,3 V du module, le reset, le bouton BOOT et le port USB.

Garder la version **N16R8** : dans les versions « …V » (R8V, R16V), GPIO47 et GPIO48 (vannes 5 et 6) passent en 1,8 V.

## Broches de U101 (module WROOM-1) — GPIO réaffectés pour le placement

Les GPIO de la v1 ont été **réaffectés** (accord du 09/10 : sans impact pour le firmware, qui n'utilise qu'une table de broches par version). Le module étant tourné (antenne à gauche), chaque signal sort du côté qui fait face à sa destination :

- **bas** (broches 1-14, vers les entrées capteur) : TLV_OUT, SPI, USB ;
- **droite** (broches 15-26, vers le bus I2C, le servo et les vannes) : I2C, DAC2_LDAC, SERVO_PWM, vannes 3 à 6 ;
- **haut** (broches 27-40, vers les optocoupleurs) : SHUTTER, FLASH_1 à 4, console UART, vannes 1 et 2.

Sur chaque côté, l'ordre des broches suit l'ordre des destinations pour que les pistes ne se croisent pas (en haut : SHUTTER vers U71 la plus proche, puis FLASH_1/2 vers U81, FLASH_3/4 vers U83, vannes 1/2 en dernier par la bande libre le long de la barrière).

| Broche module | Côté | GPIO v2 | Net | GPIO v1 |
|---|---|---|---|---|
| 1, 40, 41 (pastille) | — | — | GND | — |
| 2 | bas | — | 3V3_MCU | — |
| 3 | bas | EN | EN | — |
| 4, 5, 6, 7, 8, 9 | bas | 4, 5, 6, 7, 15, 16 | TLV_OUT_1 … TLV_OUT_6 | inchangé |
| 10 | bas | 17 | SPI_SCK | 12 |
| 11 | bas | 18 | SPI_MOSI | 11 |
| 12 | bas | 8 | libre (réserve) | I2C_SDA |
| 13 / 14 | bas | 19 / 20 | USB_DN / USB_DP | — |
| 15, 16 | droite | 3, 46 | non connectées (démarrage) | — |
| 17 | droite | 9 | libre (réserve) | I2C_SCL |
| 18 | droite | 10 | DAC2_LDAC (ancien net GPIO18) | 18 |
| 19 / 20 | droite | 11 / 12 | I2C_SCL / I2C_SDA | 9 / 8 |
| 21, 22, 23, 24 | droite | 13, 14, 21, 47 | GPIO_VALVE_6, 5, 4, 3 | 47, 48, 38, 10 |
| 25 | droite | 48 | SERVO_PWM | 13 |
| 26 | droite | 45 | non connectée (démarrage) | — |
| 27 | haut | 0 | IO0_BOOT | — |
| 28, 29, 30 | haut | 35, 36, 37 | non connectées (PSRAM octale) | — |
| 31 | haut | 38 | SHUTTER_CMD | 42 |
| 32, 33 | haut | 39, 40 | FLASH_1_CMD, FLASH_2_CMD | 17, 21 |
| 34, 35 | haut | 41, 42 | FLASH_3_CMD, FLASH_4_CMD | 39, 41 |
| 36 / 37 | haut | RXD0 / TXD0 | RXD0 / TXD0 (barrette U103) | — |
| 38 / 39 | haut | 2 / 1 | GPIO_VALVE_1 / GPIO_VALVE_2 | 1 / 2 |

Table de broches à reprendre dans le firmware v2 :

```c
// TriggerFlow v2 (module WROOM-1) — à comparer avec la table v1 (DevKit)
#define PIN_TLV_OUT_1 4   #define PIN_TLV_OUT_2 5   #define PIN_TLV_OUT_3 6
#define PIN_TLV_OUT_4 7   #define PIN_TLV_OUT_5 15  #define PIN_TLV_OUT_6 16
#define PIN_SPI_SCK   17  #define PIN_SPI_MOSI  18
#define PIN_I2C_SDA   12  #define PIN_I2C_SCL   11  #define PIN_DAC2_LDAC 10
#define PIN_SERVO_PWM 48
#define PIN_VALVE_1 2  #define PIN_VALVE_2 1  #define PIN_VALVE_3 47
#define PIN_VALVE_4 21 #define PIN_VALVE_5 14 #define PIN_VALVE_6 13
#define PIN_SHUTTER 38 #define PIN_FLASH_1 39 #define PIN_FLASH_2 40
#define PIN_FLASH_3 41 #define PIN_FLASH_4 42
```

Broches de démarrage (IO0, IO3, IO45, IO46) : seul IO0 est utilisé, pour le bouton BOOT. IO35 à IO37 restent libres (PSRAM octale). IO39 à IO42 sont aussi les broches JTAG externes, inutilisées puisque le JTAG passe par l'USB.

## Nouveaux nets

| Net | Broches |
|---|---|
| 5V_MCU | D101.1 (cathode, anode sur +5V), D102.1 (cathode, anode sur VBUS), U104.3 (VIN), C106.1 |
| VBUS | J101 A4, A9, B4, B9 ; D102.2 ; U102.5 |
| 3V3_MCU | U104.2 et languette (VOUT), U101.2, C101.1, C102.1, C104.1, C105.1, R107.1, R108.1 |
| EN | U101.3, R107.2, C103.1, SW101 (côté 1-2) |
| IO0_BOOT | U101.27, R108.2, SW102 (côté 1-2) |
| USB_DN | J101 A7 et B7, U102.1 et U102.6, U101.13 (IO19) |
| USB_DP | J101 A6 et B6, U102.3 et U102.4, U101.14 (IO20) |
| CC1 / CC2 | J101.A5 – R106.1 / J101.B5 – R105.1 |
| TXD0 / RXD0 | U101.37 – U103.2 / U101.36 – U103.3 (barrette dans la zone libre à droite des boutons, liaisons en couche Bottom) |
| GND | U101.1, 40, 41 ; U104.1 ; U102.2 ; J101 A1, A12, B1, B12 et blindage ; R106.2, R105.2 ; C103 à C106 (.2) ; SW101 et SW102 (côté 3-4) |

J101 SBU1 / SBU2 : non connectées. Le net V5_DEVKIT de la v1 devient 5V_MCU.

## Choix de conception

- **3V3_MCU dédié** : U104 AMS1117-3.3 (même pièce que U116) alimenté par 5V_MCU, séparé du +3V3 de l'électronique analogique. Le module tire jusqu'à 355 mA en émission Wi-Fi d'après la fiche JLC ; dissipation de U104 ≈ (4,55 − 3,3) × 0,36 ≈ 0,45 W en pointe, à dissiper par la languette (plage 3V3_MCU d'Inner2).
- **Deux sources pour 5V_MCU, par diodes SS14** : le +5V de la carte (D101, comme en v1) et le VBUS de l'USB (D102). Le module peut ainsi être programmé par l'USB sans le bloc 12 V, et l'USB n'alimente jamais le reste de la carte. Après la diode, 5V_MCU ≈ 4,55 V : la marge de chute de l'AMS1117 (≈ 1,1 V à pleine charge) reste juste. Si le Wi-Fi se montre instable, remplacer D101 et D102 par des diodes à plus faible tension de seuil ou passer à un régulateur à faible chute.
- **Découplage** : C101 (10 µF) + C102 (100 nF) collés à la broche 2 ; C104 + C105 (2 × 10 µF) en sortie de U104 ; C106 (10 µF) en entrée.
- **EN** : R107 10 kΩ vers 3V3_MCU + C103 1 µF vers GND (valeurs recommandées par Espressif) ; SW101 RESET vers GND.
- **IO0** : R108 10 kΩ vers 3V3_MCU ; SW102 BOOT vers GND. Maintenir BOOT puis appuyer sur RESET force le mode téléchargement.
- **USB** : un seul port USB-C, sur l'USB natif (IO19 / IO20). La v1 en avait deux (pont série + USB natif). La programmation passe par l'USB-Serial/JTAG intégré. Si le firmware utilise l'USB natif pour le contrôle PC, on reprogramme avec BOOT + RESET, et la console série reste accessible sur la barrette U103 (GND, TX, RX) avec un adaptateur 3,3 V. R106 / R105 (5,1 kΩ) déclarent la carte comme périphérique USB-C. U102 protège les deux lignes et VBUS contre les décharges.
- **Supprimés** : la DevKit et ses deux barrettes femelles. D101 reste (même rôle : +5V vers l'alimentation du microcontrôleur).

## BOM de la feuille MCU v2

| Réf. | Pièce | Boîtier | LCSC | Catégorie JLC |
|---|---|---|---|---|
| U101 | ESP32-S3-WROOM-1-N16R8 | SMD 25,5 × 18 mm | C2913202 | Extended (à confirmer sur la fiche) |
| U104 | AMS1117-3.3 | SOT-223 | C6186 | (déjà dans la BOM v1, U116) |
| U102 | USBLC6-2SC6 | SOT-23-6 | C7519 | à vérifier |
| J101 | HRO TYPE-C-31-M-12 (16 broches) | SMD | C165948 | Extended |
| SW101, SW102 | TS-1187A-B-A-B (5,1 × 5,1 mm) | SMD | C318884 | Basic |
| D101, D102 | SS14 | SMA | C2480 | (déjà dans la BOM v1) |
| R107, R108 | 10 kΩ | 0603 | C25804 | (déjà dans la BOM v1) |
| R106, R105 | 5,1 kΩ | 0603 | C23186 | Basic |
| C103 | 1 µF | 0603 | C5673 | (déjà dans la BOM v1) |
| C102 | 100 nF | 0603 | C14663 | (déjà dans la BOM v1) |
| C101, C104, C105, C106 | 10 µF | 0805 | C15850 | (déjà dans la BOM v1) |
| U103 | barrette mâle 1 × 3, pas 2,54 mm (1 GND, 2 TXD0, 3 RXD0) | traversant | C5383112 | non montée (Add into BOM : No) |

Les numéros LCSC de U101, U102, J101, SW101/142 et R106/144 ont été vérifiés sur les fiches JLC / LCSC le 06/10/2026. Les autres sont repris de la BOM v1 exportée d'EasyEDA.

## Implantation (voir `pcb/`)

- U101 tourné de 90° : **antenne au bord gauche** (x = 0,5 à 6,8 mm), broches 1 à 14 vers les entrées capteur, 15 à 26 vers le bus I2C, 27 à 40 vers les optocoupleurs.
- Colonne de droite reprise de l'implantation EasyEDA du 09/10 : servo, relais et entrée 12 V à l'arrière ; vannes au milieu ; 12 V → 5 V et +3V3 dans le coin avant droit, avec la boucle de découpage de U115 compacte (C117 au-dessus de l'entrée, C118-C120 et D113 collés aux broches, L112 à moins de 10 mm).
- Bus I2C (U111 à U114) hors du couloir de bus, R114 / R115 près de U111.
- Zone antenne interdite au cuivre sur les 4 couches : x 0 à 7, y 43,5 à 68 mm (repère du placement). Plus de fente fraisée.
- J101 au bord gauche sous la zone antenne (y 70,3 à 79,7), U102 juste derrière, R106 / R105 à côté.
- U104, D101, C104 à C106, R108, SW101 et SW102 dans la zone libérée par la DevKit (x 27 à 56).
- Inner2 : nouvelle plage **3V3_MCU** (x 9 à 50, y 45,5 à 72,5) ; la plage +3V3 commence à x = 52 au-dessus du couloir de bus ; la bande gauche du +5V disparaît et le tronçon sous la barrière est prolongé jusqu'à D101 (x = 28) ; la plage **+12V** descend jusqu'à l'entrée de U115 (coin avant droit) et le **+5V** occupe le bas du coin (sortie de L112, C122, U116).

## Points à vérifier

- Orientation réelle de l'empreinte EasyEDA du module (position de la broche 1 et de l'antenne) avant de figer la rotation.
- Distance entre l'antenne et le blindage de l'USB-C (≈ 7 mm) : acceptable, à surveiller si la portée Wi-Fi est faible.
- Lignes USB_DP / USB_DN : courtes, de même longueur, sans via, au-dessus du plan GND d'Inner1.
- La zone x 56 à 88 de l'ancienne antenne est maintenant libre : la carte pourrait rétrécir dans une version suivante.

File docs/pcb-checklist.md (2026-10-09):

# TriggerFlow — Checklist de placement PCB

4 octobre 2026 (mise à jour d'après le placement réel) — export de la checklist « TriggerFlow — Checklist de placement PCB »

## Plan de zones (placement du 04/10)

Carte 175 × 125 mm, 4 couches, vue de dessus. Origine au coin arrière gauche, x vers la droite, y vers l'avant (bord arrière en haut). Cotes en mm, reprises du placement réel (`pcb/placement_TriggerFlow.csv`), à affiner une fois les empreintes confirmées. Positions des connecteurs données par leur **centre**.

| Zone | x (mm) | y (mm) | Contenu |
| --- | --- | --- | --- |
| Sorties isolées (VISO) | 0–99 | 0–40 | J71, J81-J84 (centres x = 17, 35, 53, 71, 89) ; TVS, 2N7002, 74LVC2G04 ; U118 au centre de l'îlot |
| Barrière d'isolation | 0–99 | y = 40 | U71, U81, U83 (HCPL-063L) et U117 (B0505S, sous J84, x = 90) à cheval ; ≥ 3 mm sans cuivre, toutes couches |
| Servo, relais, entrée 12 V | 104–175 | 0–43,5 | bord arrière : J131 (servo) + C136, J132 (relais), J112 (12 V) ; RELAY131, Q131, D132 ; U131 (languette à gauche) + L131, C134, D131 ; F112, Q112, D112 au bord droit |
| Module ESP32-S3-WROOM-1 (U101, v2) | 0,5–26 | 45–63 | tourné de 90°, antenne au bord gauche, broches 1-14 vers l'avant |
| USB-C J101, U102 (v2) | 0,5–16 | 70–80 | USB natif protégé, CC1 / CC2 5,1 k |
| 3V3_MCU, RESET, BOOT (v2) | 27–56 | 44,5–72,5 | U104, D101, D102, SW101, SW102 |
| Zone antenne (v2) | 0–7 | 43,5–68 | sans cuivre sur les 4 couches ; plus de fente |
| Bus I2C (bloc 8) | 88–124 | 46–72 | U111 MCP23017, U112/U113 MCP4728, U114 ADS7828 |
| Couloir de bus | 0–124 | 73,5–81,5 | THR, CS, ID, TLV_OUT en couche 4 ; rangée de vias de couture côté analogique (y ≈ 81,6) |
| Vannes 2 × 3 | 127–175 | 44–88 | CN91-CN93 (y ≈ 48) et CN94-CN96 (y ≈ 83) vers l'extérieur, rail +12V au milieu ; D9n entre CN9n et Q9n |
| Entrées capteur ×6 | 0–124 | 82–125 | J11-J61 (centres x = 17, 35, 53, 79, 97, 115) ; une bande de 18 mm par voie |
| 12 V → 5 V, +3V3, LED | 124–175 | 90–125 | U115 tourné (broches à gauche, languette au bord droit), C117 au-dessus de l'entrée, C118-C120 et D113 collés aux broches, L112 et C122 à gauche ; U116, C121, C116, CN111 au bord avant |

Trous M3 : H1 (4, 4) et H5 (101, 6) côté VISO en NPTH ; H2 (171, 4), H3 (4, 121), H4 (171, 121), H6 (66, 121) entre J31 et J41 ; H7 supprimé (il coupait la bande +5V d'Inner2).

## Partitionnement et chemins de courant

Analogique, numérique, puissance et isolé restent dans leurs zones ; aucun courant fort ne passe sous l'analogique.

- [ ] Couche 2 = GND plein, jamais coupée sous les bandes analogiques ni sous la zone I2C
- [ ] Couche 3 : +3V3 au centre et à l'avant (entrées, I2C) ; v2 : plage 3V3_MCU sous le module et U104 ; +12V limité au quart droit (alim, relais, servo, vannes) ; +5V en bandes étroites le long des bords (avant sous les RJ45 vers F11-F61, bande verticale de 4,5 mm vers U116, tronçon sous la barrière vers U117 et D101) ; v2 : plus de bande gauche ; VISO_3V3 dans l'îlot
- [ ] Retours des vannes, du servo et du LM2596 vers J112 par le quart droit uniquement
- [ ] Une piste qui traverse une bande analogique passe en couche 4 et la croise à angle droit
- [ ] Chaque voie d'entrée suit l'ordre du signal : RJ45 → TVS/PTC → R16/BAT54S → MCP6S91 → TLV3501 → TLV\_OUT vers l'ESP32
- [ ] TLV\_OUT (fronts de 4,5 ns) ne longe jamais l'entrée CLAMP du PGA
- [ ] SPI, CS et SERVO\_PWM routés en couche 4, hors des bandes analogiques
- [ ] Pistes +12V, VALVE\_PWR, VALVE\_SW : ≥ 2 mm ou plages de cuivre
- [ ] Au moins 2 vias par source de MOSFET (Q91-Q96, Q131) vers la couche 2

## Antenne de l'ESP32 (v2 : module au bord)

En v2, l'antenne du module est au bord gauche de la carte, comme le recommande Espressif. Le problème de la v1 (antenne vers l'intérieur, près des voies analogiques) disparaît.

- [ ] Zone x 0–7, y 43,5–68 sans cuivre sur les 4 couches, sans composant ni piste
- [ ] Partie antenne du module (x 0,5–6,8) au ras du bord, rien au-delà
- [ ] Aucun composant métallique (USB-C, électrolytique) à moins de 5 mm de la zone antenne ; J101 est à ≈ 2 mm de la zone et ≈ 7 mm de l'antenne : à surveiller
- [ ] Plan GND d'Inner1 plein sous le corps du module (hors antenne), avec de nombreux vias sous la pastille centrale (broche 41)
- [ ] Couloir de bus (y 73,5–81,5) entre le module et les voies analogiques, rangée de vias de couture côté analogique
- [ ] Si le boîtier est métallique : module WROOM-1U-N16R8 (C3013946) à antenne externe u.FL

## Empilement 4 couches

Dans l'empilement JLC 1,6 mm, les couches 3 et 4 sont proches (≈ 0,2 mm) et séparées des couches 1-2 par un noyau épais : une piste de couche 4 prend son retour de courant dans la couche 3, pas dans le plan GND.

- [ ] Empilement JLC04161H-7628 : L1 composants et signaux, L2 GND plein, L3 alimentations, L4 signaux longs
- [ ] Aucune piste de couche 4 ne traverse une frontière entre plages de la couche 3 ; sinon condensateur 100 nF entre les deux plages au point de croisement, ou passage en couche 1
- [ ] SERVO_PWM et GPIO_VALVE_1 à 6 : couche 4 sous le +3V3, via, puis couche 1 avant d'entrer dans la zone +12V
- [ ] GND coulé sur les zones libres des couches 1 et 4, relié à la couche 2 par des vias, aussi le long du bord de la carte
- [ ] Dans l'îlot isolé, même chose en VISO_GND, avec ses propres vias vers l'îlot VISO_GND de la couche 2

## Isolation VISO

Une seule barrière droite à y = 40 mm ; seuls les optos et le B0505S la traversent.

- [ ] Écart ≥ 3 mm entre cuivre GND et cuivre VISO, sur les 4 couches, tout le long de la barrière
- [ ] U71, U81, U83 (HCPL-063L) et U117 (B0505S) posés à cheval, broches côté ESP32 sous la barrière
- [ ] Bande sans cuivre sous U117 entre les broches 1-2 et 3-4 (fente fraisée optionnelle)
- [ ] Aucune piste, aucun via, aucun plan qui traverse la barrière en dehors de ces 4 composants
- [ ] Blindages des RJ45 J71 et J81-J84 non connectés
- [ ] Trous H1 et H5 en NPTH (non métallisés), à ≥ 3 mm de tout cuivre VISO
- [ ] Écart ≥ 3 mm entre la zone relais (GND) et l'îlot VISO
- [ ] Vérifier la distance de fuite réelle sous les HCPL-063L (boîtier SO-8) au regard de la norme IPC-2221B

## Découplage, puissance et thermique

Les deux LM2596 dissipent chacun 2 à 3 W dans le même coin : boucles courtes, cuivre sous les languettes, électrolytiques à distance.

- [ ] Chaque 100 nF à ≤ 2 mm de sa broche d'alimentation, via GND juste à côté du condensateur
- [ ] Filtre THR (R13/C11 et équivalents) collé à la broche 2 de chaque TLV3501
- [ ] Boucle C117 → U115 → D113 la plus courte possible, L112 à moins de 10 mm de la broche SW de U115 ; idem C131/C132/C133 → U131 → D131 et L131
- [ ] L112 et L131 orientées à 90° l'une de l'autre, à ≥ 10 mm
- [ ] Plage de cuivre et ≈ 15 vias thermiques sous la languette de U115 et de U131 (deux plans internes à traverser) ; couche 3 reliée au GND sous les régulateurs pour dissiper
- [ ] Électrolytiques C117, C122, C134, C136 à ≥ 5 mm des languettes des LM2596
- [ ] C136 (470 µF) au plus près de J131
- [ ] Dans chaque canal vanne, D9n entre CN9n et Q9n : boucle de roue libre ≤ 10 mm
- [ ] v2 : C101 + C102 collés à la broche 2 (3V3) du module ; C104 / C105 en sortie de U104 ; R107 / C103 près de EN
- [ ] v2 : USB_DP / USB_DN courtes, de même longueur, sans via, au-dessus d'Inner1 ; U102 entre J101 et le module

## Mécanique et fixations

Onze RJ45 subissent un effort à chaque branchement : un trou de fixation près de chaque groupe de connecteurs, pas seulement aux coins.

- [ ] 6 trous M3 (H1 à H6) ; H7 supprimé, il coupait la bande +5V d'Inner2
- [ ] Zone d'exclusion de 7 mm de diamètre autour de chaque trou (tête de vis, entretoise)
- [ ] Décider si les trous GND (H2, H3, H4, H6) sont reliés à la masse du boîtier ; H1 et H5 jamais
- [ ] RJ45 alignés sur le bord, nez au ras ou en léger débord selon la façade
- [ ] Dégagement de 5 mm autour de CN91-CN96, J131 et J132 pour les doigts
- [ ] Rien de haut contre les connecteurs de vannes (C136, RELAY131)
- [ ] Relever les hauteurs maximales : relais, électrolytiques, LM2596 (v2 : plus de DevKit sur barrettes) ; vérifier sous le couvercle
- [ ] Découpe de façade pour l'USB-C J101 au bord gauche (v2 : un seul port)

## Fabrication, points de test et sérigraphie

Tout sur la face du dessus pour un assemblage JLC en simple face, le moins cher.

- [ ] Tous les CMS et tous les traversants (RJ45, borniers, barrettes) sur la face du dessus
- [ ] Composants polarisés orientés dans le même sens par zone (diodes, électrolytiques, CI)
- [ ] 3 repères optiques (fiducials) en coins opposés
- [ ] ≥ 0,5 mm entre tout cuivre et le bord de la carte
- [ ] Écarts entre zones d'encombrement selon IPC-7351 ; pas de CMS sous les zones de soudure des traversants
- [ ] Points de test : +12V, +5V, +3V3, VISO\_3V3, V\_SERVO, GND, VISO\_GND, I2C\_SDA/SCL, SPI\_MOSI/SCK, TLV\_OUT\_1 à 6
- [ ] Sérigraphie : V1 à V6 et + / − près de CN91-CN96, dans l'ordre des GX12 de façade
- [ ] Sérigraphie : « BASSE TENSION, 30 V max, jamais de 230 V » près de J132
- [ ] Sérigraphie : numéro de voie près de chaque RJ45, marquage de la zone isolée
- [ ] Empilement JLC standard 4 couches 1,6 mm, cuivre 1 oz

## À confirmer avant le placement réel

Les cotes du plan sont estimées ; ces données les figent.

- [ ] Empreinte exacte du RJ45 HanXia C25168869 (largeur supposée 16 mm, pas de 18 mm)
- [ ] Empreinte EasyEDA du module WROOM-1 : position de la broche 1 et de l'antenne, pour fixer la rotation
- [ ] HX25003-2A : version droite ou coudée
- [ ] Boîtier : plastique ou métallique (décide de la WROOM-1U et du raccordement des trous à la masse)
- [x] Borniers J131 (servo) et J132 (relais) : KF128-5.08-3P-AA, C474953
- [x] Mise à jour de README.md et BOM-netlist.md sur GitHub (servo, relais, suppression des Blocs 4 et 7)

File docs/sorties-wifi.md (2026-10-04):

# Sorties Wi-Fi — prises connectées (remplacent le Bloc 6 « relais »)

Décision du 03/10/2026 (révisée le 04/10) : les 3 sorties relais sur RJ45 sont supprimées ; **une seule sortie relais** est conservée sur bornier (Bloc 13). Les usages prévus (éclairage, petit compresseur) sont des appareils **secteur sans contrainte de timing** : ils sont pilotés par des prises connectées Wi-Fi commandées par l'ESP32 en réseau local.

## Pourquoi

- **Sécurité** : aucun 230 V dans le boîtier ; la commutation secteur est faite par un appareil déjà certifié.
- **Souplesse** : nombre de sorties non limité, pas de câble supplémentaire vers le boîtier.
- **Carte simplifiée** : 3 relais, 3 transistors, 3 RJ45 en moins (12 RJ45 au lieu de 15) ; lignes MCP23017 GPB2-GPB4 libérées.

## Matériel recommandé

| Usage | Prise | Remarque |
|---|---|---|
| Éclairage | Shelly Plug S, Shelly 1 / 1PM (encastré), ou prise Tuya reflashée Tasmota / ESPHome | API locale obligatoire (sans cloud) |
| Petit compresseur | Prise **≥ 10 A** (Shelly Plug S 10 A / 2 500 W, Shelly 1PM 16 A) | Moteur : fort appel de courant au démarrage |

## Réseau : l'ESP32 crée son propre Wi-Fi

L'ESP32 fonctionne en **point d'accès (SoftAP)** : il crée le réseau « TriggerFlow » et sert de serveur DHCP. Les prises s'y connectent directement, **sans box ni routeur : fonctionne partout**, y compris en extérieur (là où il y a une prise de courant pour l'appareil commandé). Le téléphone de l'utilisateur rejoint le même réseau pour l'application web. En option, mode AP + STA : connexion simultanée à la box domestique quand elle est disponible (mises à jour).
Limites : 4 clients par défaut, ~10 en configuration ; portée de quelques dizaines de mètres.

## Commande depuis l'ESP32

- Réseau local uniquement (réseau de l'ESP32), adresses IP fixes attribuées par le DHCP de l'ESP32 (ou mDNS).
- Shelly (Gen1) : `GET http://<ip>/relay/0?turn=on|off` ; Shelly Gen2/Plus : `GET http://<ip>/rpc/Switch.Set?id=0&on=true|false`.
- Tasmota : `GET http://<ip>/cm?cmnd=Power%20On|Off` ; ou MQTT (`cmnd/<topic>/POWER`).
- ESPHome : API REST du serveur web embarqué ou MQTT.
- Variante possible : passer par un serveur Home Assistant (API REST locale) si l'installation en dispose.

## Contraintes firmware

- **Latence 50–500 ms, variable** : réservé aux actions non critiques (allumer / éteindre avant ou après une séance, couper l'éclairage d'ambiance avant une prise au flash…).
- Les commandes sont envoyées **avant ou après** une séquence de déclenchement, **jamais pendant** : l'activité Wi-Fi (cœur 0) peut ajouter de la gigue aux interruptions du cœur 1.
- Gestion des erreurs : délai d'attente court (≈ 1 s), retour d'état affiché dans l'application, pas de blocage du moteur de règles si une prise ne répond pas.

## Besoins qui ne passent pas par une prise Wi-Fi

| Besoin | Solution |
|---|---|
| Charge 12 V DC (ruban LED, ventilateur, pompe, électrovanne en plus) | une **sortie vanne libre** : 12 V, 1,1 A (PTC), PWM possible, non isolée, broche 1 = +12V, broche 2 = commutée à la masse |
| Contact sec basse tension (entrée d'un autre appareil) | **module relais 12 V** du commerce branché sur une sortie vanne libre |
| Contact isolé basse tension DC, polarisé (≤ 24 V, quelques centaines de mA) | une sortie flash libre (Bloc 2, isolée) |
| Timing précis (< 1 ms) | sorties de la carte uniquement (flash, vannes, servo) |
| Contact sec embarqué, sans configuration réseau | **sortie relais** de la carte (Bloc 13, HF32F, 3 A / 30 V DC, basse tension uniquement) |
| Lumière 12 V dimmable | une **sortie vanne libre** en mode « lumière » (PWM ≈ 20 kHz, 1,1 A max) |

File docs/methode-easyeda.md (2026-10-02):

# Méthode EasyEDA Pro + Claude Code (testée le 30/09 - 01/10/2026)

## Résultat
Le Bloc 2 (flash / caméra) a été généré dans EasyEDA Pro avec easyeda-copilot. Netlist exportée et vérifiée par comparaison avec la référence : conforme (seuls les noms de nets INPUT_A/B changent). Mise en page lisible, quelques retouches manuelles de textes à faire.

## Ce qui a marché
- Outils : extension EasyEda Copilot (biosshot) dans EasyEDA Pro application bureau (>= 3.2.149) + serveur MCP `easyeda-copilot` ajouté avec `claude mcp add --scope user easyeda-copilot -- npx easyeda-copilot-mcp`.
- Case « Allow interactive with external » cochée dans Extensions Manager > EasyEda Copilot > Config (et pour Run API Gateway).
- Menu Advanced > Copilot > MCP = interrupteur de recherche du serveur (scan stopped = arrêté, recliquer).
- Session Claude Code neuve (/clear ou /exit puis claude), projet EasyEDA vide, feuille de schéma active, aucun dialogue ouvert.
- Pièces données par référence LCSC explicite (jamais par nom : l'agent a posé un ESP32 et des AMS1117 à la place de l'optocoupleur).
- Consigne « au premier échec d'appel, arrête-toi et dis-moi lequel ».
- Vérification : exporter la netlist (menu Export) et la comparer soi-même. Ne JAMAIS se fier au résumé de l'agent (il a annoncé « généré ✓ » sans rien dessiner, et « netlist intacte » avant d'exécuter).

## Ce qui n'a pas marché
- Déplacer des composants avec SCH_PrimitiveComponent.modify : les fils et labels ne suivent pas, le schéma est cassé.
- easyeda-enhanced-schematic-skill (officiel) : place des cadres colorés mais superpose les textes ; à sortir du dossier ~/.claude/skills pour qu'il ne soit pas choisi.
- serveurs jlcmcp / easyeda-mcp-pro : pas d'outil de placement précis côté schéma. Désactiver les serveurs MCP EasyEDA quand on ne s'en sert pas.
- Mise en page automatique ou demande de réarrangement : toujours refaire à la souris (les fils suivent dans l'éditeur).

## Références LCSC vérifiées
| Pièce | Référence LCSC |
|---|---|
| HCPL2631 (DIP-8, onsemi) | C16384 |
| 2N7002 SOT-23 | C8545 |
| Résistance 270 Ohm 0603 | C22966 |
| Résistance 10 kOhm 0603 | C25804 |
| Résistance 220 Ohm 0603 | C22962 |
| AO3400A SOT-23 | C20917 |
| Diode SS14 SMA | C2480 |
Les références du doc « Bloc 3 - Sorties Électrovannes » (C160122, C25057, C25761) ne sont pas fiables : utiliser le tableau ci-dessus.

## Bloc 3 : attention
Le fichier sortie_electrovanne.kicad_sch d'origine a ses connexions cassées (résistances et grilles non reliées, diode court-circuitée). Refaire le bloc depuis la netlist voulue (voir la consigne dans la conversation du 01/10/2026) : GPIO -> 220 Ohm -> grille ; pull-down 10 kOhm grille -> GND ; source -> GND ; drain -> VALVE_OUT ; SS14 flyback (cathode V12, anode drain). Les descriptions « pull-up » du fichier d'origine sont erronées.

## Générateur KiCad
Reste la référence pour des schémas propres et vérifiés (claude/generateur/). Variante EasyEDA : EASYEDA=1 python3 build_project.py retire les champs cachés (Description, Datasheet, Footprint) qu'EasyEDA affiche à l'import.

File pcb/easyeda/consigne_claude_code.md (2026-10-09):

# Consigne à donner à Claude Code (session neuve, easyeda-copilot actif, PCB TriggerFlow ouvert sur une copie)

Exécute le script `triggerflow_plans_et_zones.js` dans l'éditeur PCB EasyEDA Pro, en deux temps :
1. D'abord avec `DRY_RUN = true` : montre-moi la ligne « Calibration » (1 mm doit valoir 39,37 unités si l'API est en mil, échelles X et Y égales en valeur absolue).
2. Si la calibration est cohérente, passe `DRY_RUN = false` et exécute. Montre-moi le journal complet (lignes OK / ÉCHEC).
Au premier appel d'API qui échoue ou n'existe pas (par exemple `eda.pcb_PrimitivePad.getAll` ou le format du polygone), arrête-toi et dis-moi lequel, sans improviser de contournement.
Ne modifie rien d'autre dans le projet.

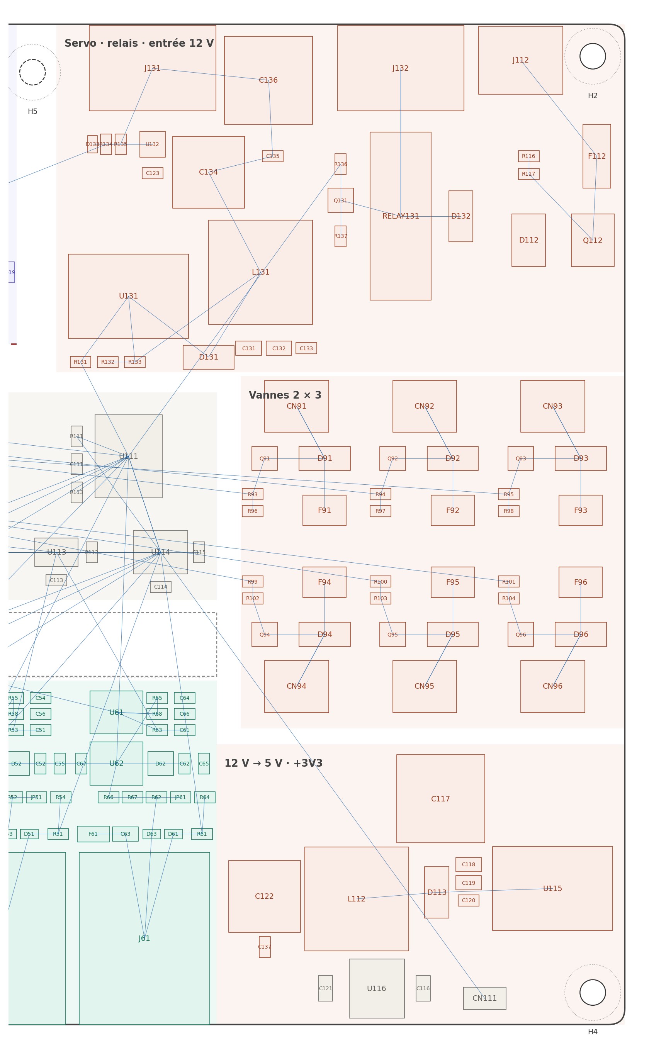
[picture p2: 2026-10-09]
pcb/zoom_puissance.png

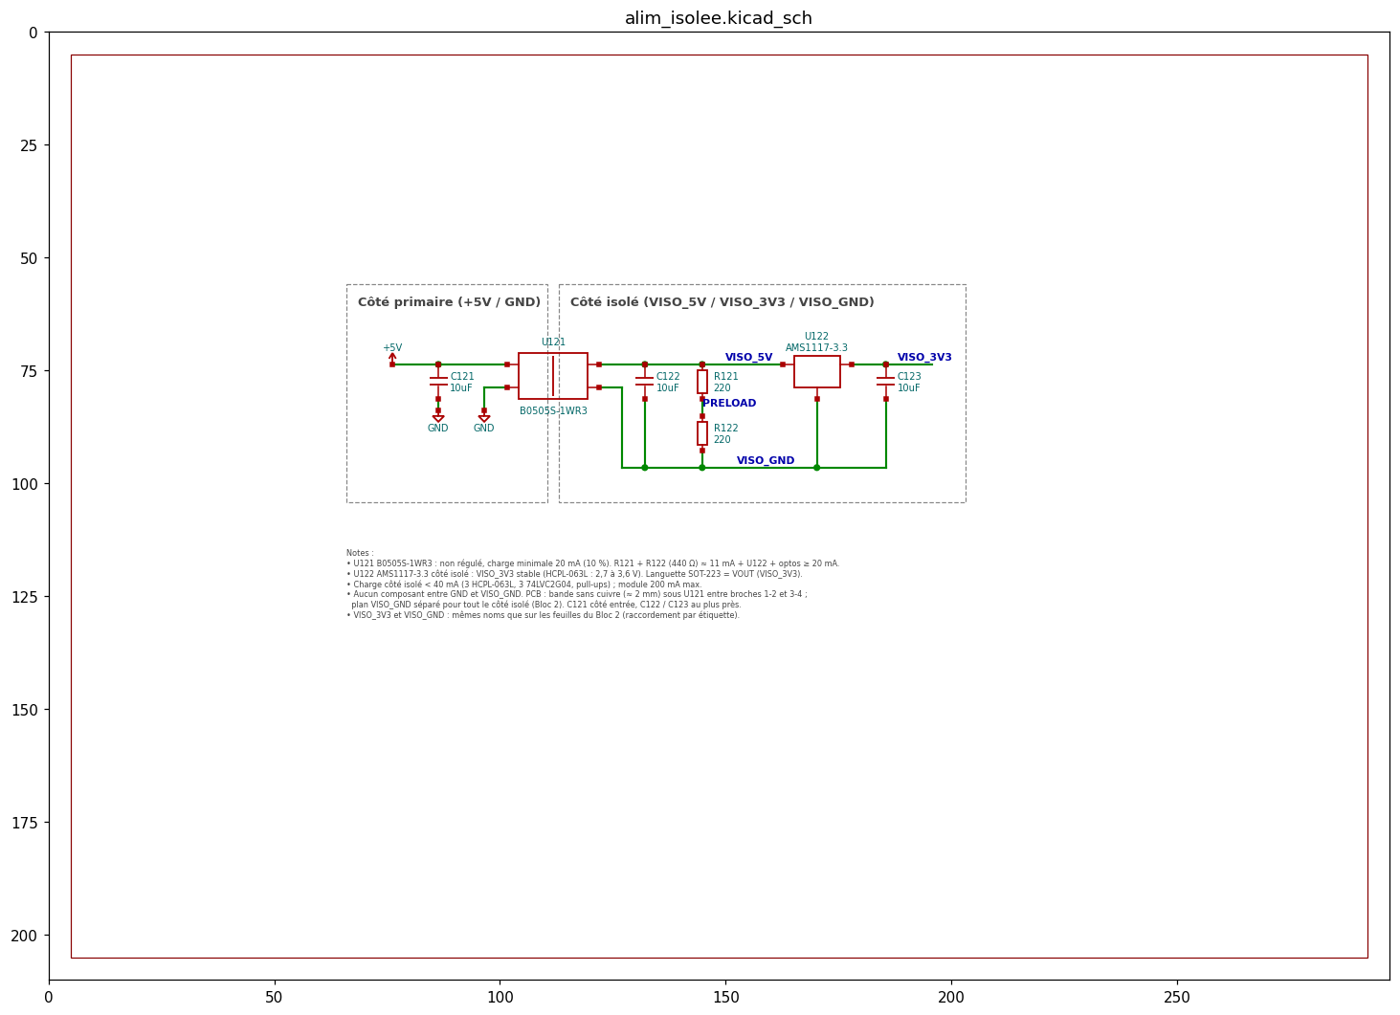
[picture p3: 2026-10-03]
kicad/bloc5b_alim_isolee/apercu.png

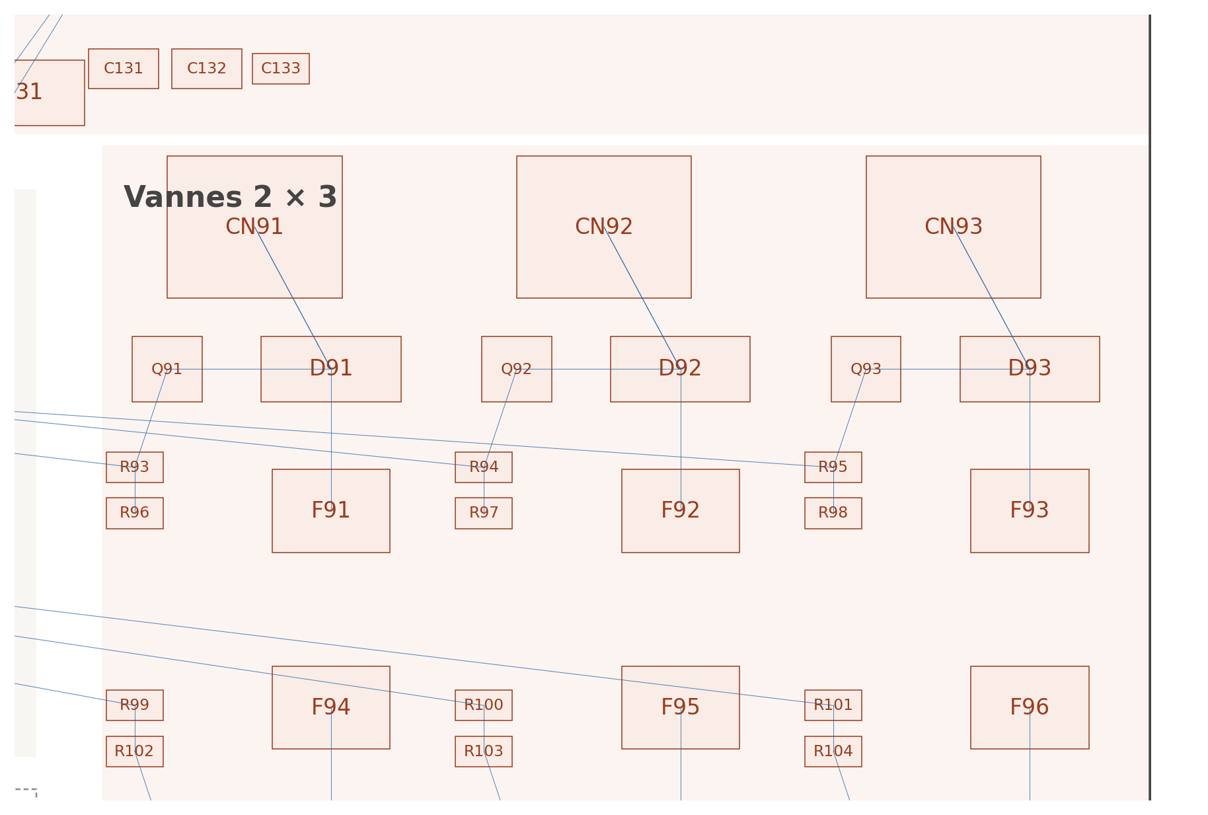
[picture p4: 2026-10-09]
pcb/zoom_servo.png

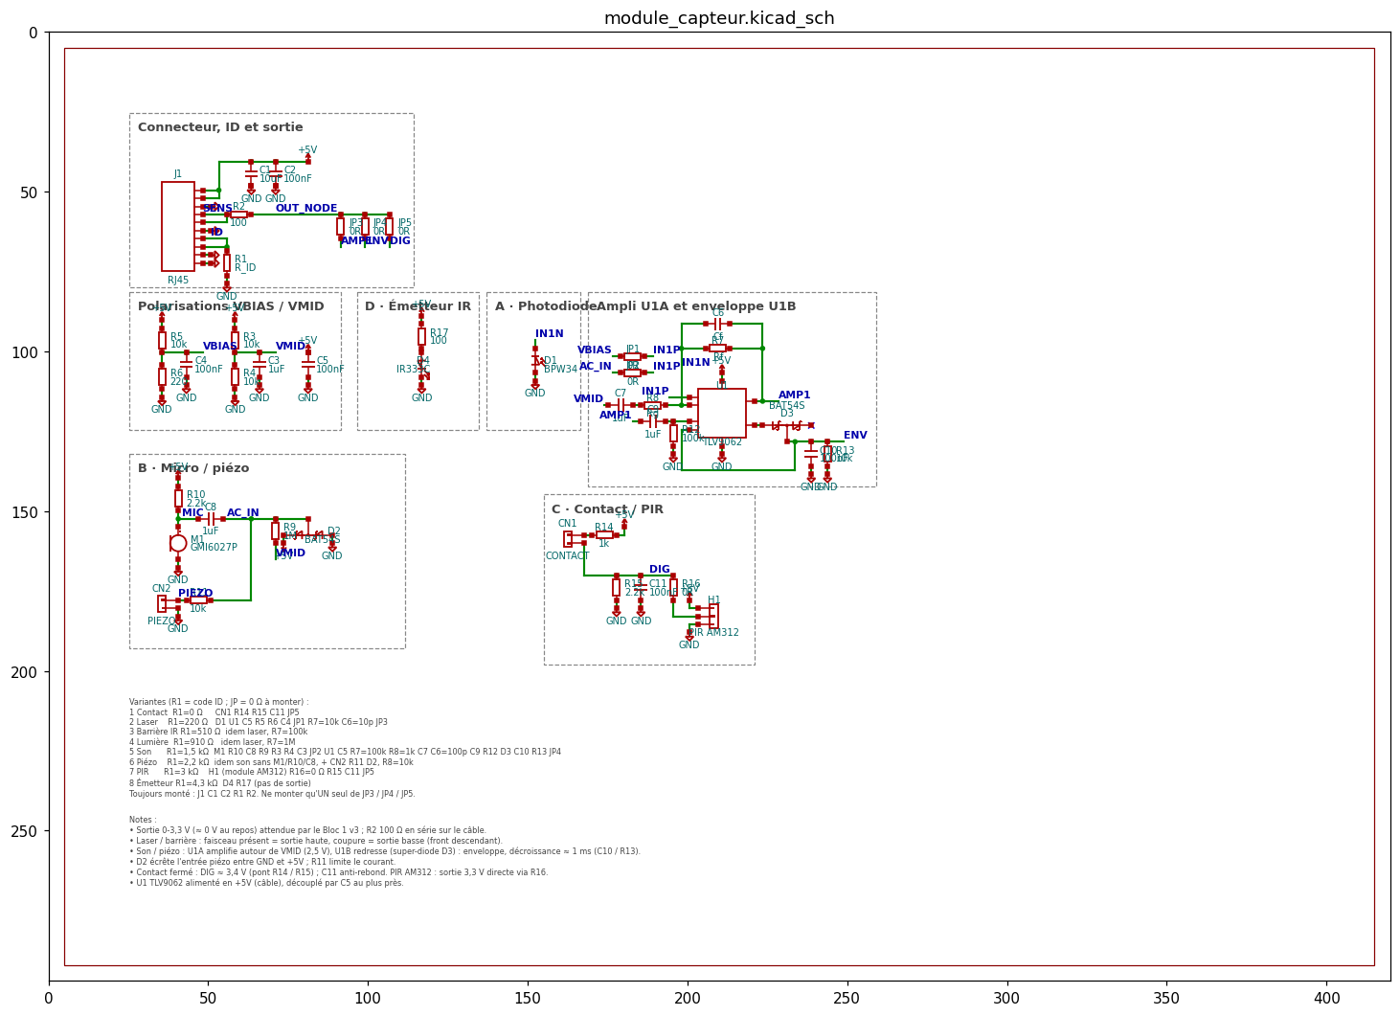
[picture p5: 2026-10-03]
kicad/module_capteur/apercu.png

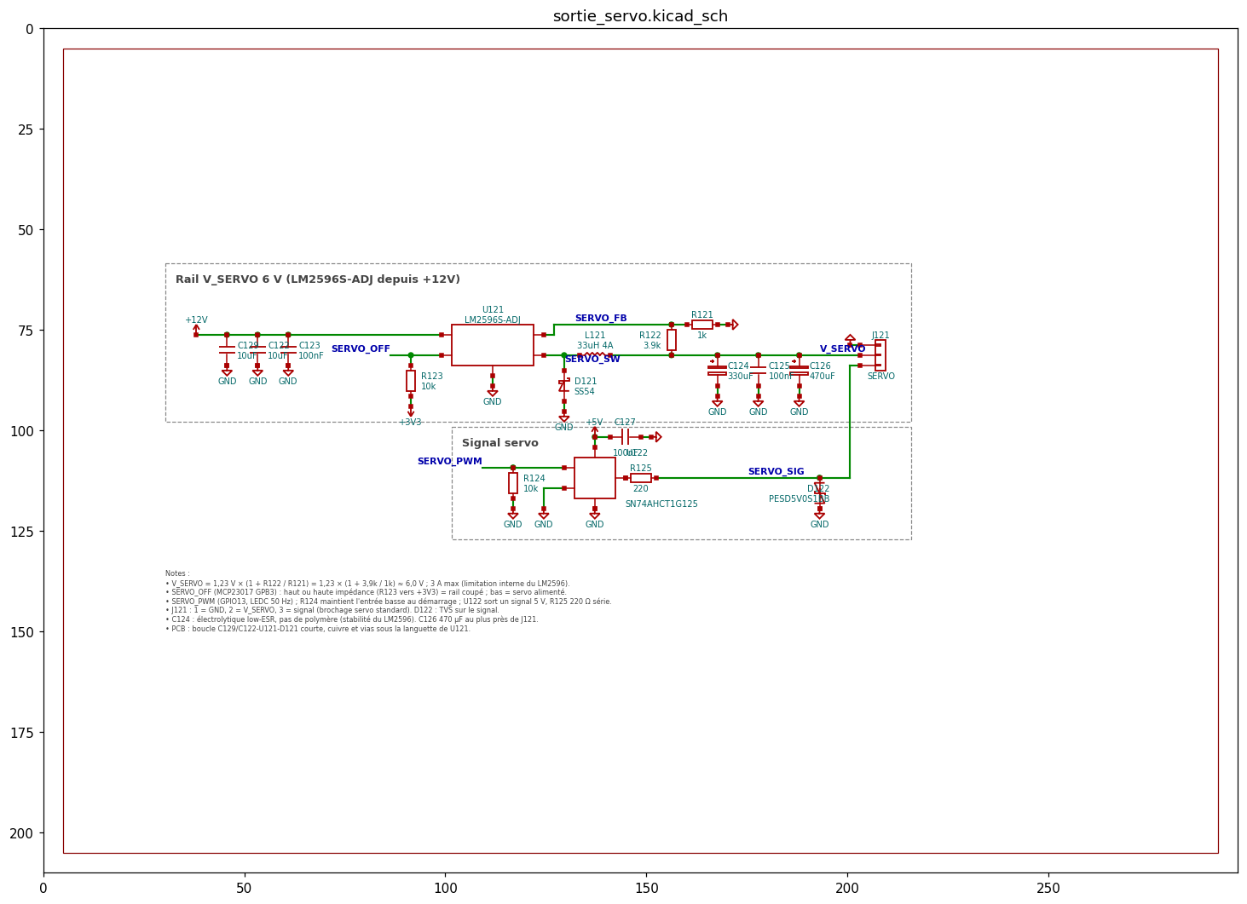
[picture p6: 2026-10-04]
kicad/sortie_servo/apercu.png

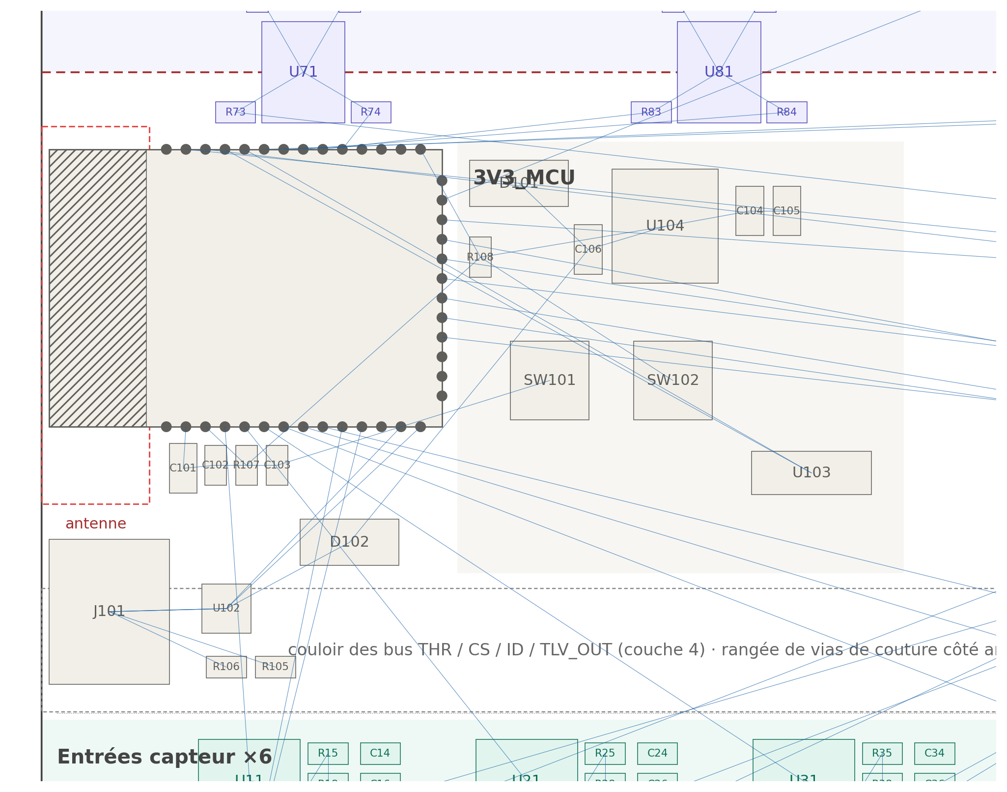
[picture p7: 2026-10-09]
pcb/zoom_mcu_v2.png

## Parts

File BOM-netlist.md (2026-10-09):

# TriggerFlow — BOM et netlists par bloc

État au **05/10/2026**. Référence : export netlist EasyEDA du 05/10/2026 (`netlist/Netlist_Schematic1_2026-10-05.tel`), vérifié net par net, ERC EasyEDA : 0 erreur, 0 avertissement ; contrôle automatique : aucun net de voie (SENSOR, CLAMP, CS, THR, TLV_OUT, ID, GATE, VALVE…) mélangé entre deux voies.
Numérotation : chiffre(s) de page + index (page 1 = voie 1 → R11, U11… ; page 9 = vannes ; page 10 = ESP32 / Bloc 8 ; page 11 = Blocs 5 et 5b ; page 12 = sorties servo et relais). Quand une page dépasse 9 pièces d'un même type, la numérotation déborde (R100…R104 = vannes) : se fier au schéma, pas au numéro.

## État de validation

| Bloc | Contenu | État |
|---|---|---|
| 1 | 6 entrées capteur v3 (+ protection des lignes ID) | ✅ validé (6 voies) |
| 2 | 6 sorties isolées : 4 flash + appareil photo (focus, shutter) | ✅ validé (avec inverseurs et TVS) |
| 3 | 6 électrovannes + connecteurs | ✅ validé |
| 4 | Moteur pas à pas | ❌ **supprimé** (04/10) |
| 5 | Alimentation 12 V → +12V / +5V / +3V3 | ✅ validé |
| 5b | Alimentation isolée VISO_3V3 / VISO_GND | ✅ validé |
| 6 | Relais ×3 sur RJ45 | ❌ **supprimé** → prises Wi-Fi + 1 relais (Bloc 13) |
| 7 | PWM lumière / servo | ❌ **supprimé** (04/10) : lumière 12 V par une sortie vanne, servo dédié (Bloc 12) |
| 8 | Bus I2C : MCP23017, 2 × MCP4728, ADS7828, LED de statut | ✅ validé |
| 9 | Module capteur universel (carte déportée, 8 variantes) | 📝 schéma KiCad généré (`kicad/module_capteur/`) |
| 10 | Protection ESD des connecteurs | ✅ validé |
| 11 | PTC | intégrées dans chaque bloc (F11-61, F91-96) |
| 12 | Sortie servo, rail 6 V dédié | ✅ validé (page 12) |
| 13 | Sortie relais (contact sec) | ✅ validé (page 12) |
| PCB | Implantation 175 × 125 mm, 4 couches | 📝 placement v4 recalé sur la netlist du 05/10 (`pcb/`), checklist (`docs/pcb-checklist.md`) |
| ESP32 | Feuille U101 (YD-ESP32-S3 N16R8) | ✅ validé |

Méthode : schéma de référence → saisie EasyEDA Pro avec références LCSC → export netlist (.tel) → comparaison net par net.

---

## Feuille MCU v2 — U101 ESP32-S3-WROOM-1-N16R8 (branche v2-wroom)

Le module remplace la DevKit de la v1 ; chaque signal garde son GPIO. Détail complet (broches, nets, choix, BOM vérifiée) : [docs/mcu-v2-wroom.md](docs/mcu-v2-wroom.md).

GPIO réaffectés pour le placement (09/10) : chaque signal sort du côté du module qui fait face à sa destination.

| Broche module | GPIO | Net |
|---|---|---|
| 4 à 9 | 4, 5, 6, 7, 15, 16 | TLV_OUT_1 … TLV_OUT_6 |
| 10 / 11 | 17 / 18 | SPI_SCK / SPI_MOSI |
| 13 / 14 | 19 / 20 | USB_DN / USB_DP |
| 18 | 10 | DAC2_LDAC |
| 19 / 20 | 11 / 12 | I2C_SCL / I2C_SDA |
| 21, 22, 23, 24 | 13, 14, 21, 47 | GPIO_VALVE_6, 5, 4, 3 |
| 25 | 48 | SERVO_PWM |
| 27 | 0 | IO0_BOOT |
| 31 | 38 | SHUTTER_CMD |
| 32, 33, 34, 35 | 39, 40, 41, 42 | FLASH_1_CMD … FLASH_4_CMD |
| 36 / 37 | RXD0 / TXD0 | barrette U103 (broches 3 / 2) |
| 38 / 39 | 2 / 1 | GPIO_VALVE_1 / GPIO_VALVE_2 |
| 2 / 3 | — | 3V3_MCU / EN |
| 1, 40, 41 | — | GND |
| 12, 17 | 8, 9 | libres (réserve) |

| Réf | Pièce | LCSC |
|---|---|---|
| U101 | ESP32-S3-WROOM-1-N16R8 | C2913202 |
| U104 | AMS1117-3.3 (3V3_MCU) | C6186 |
| U102 | USBLC6-2SC6 | C7519 |
| J101 | USB-C HRO TYPE-C-31-M-12 | C165948 |
| SW101, SW102 | TS-1187A-B-A-B (RESET, BOOT) | C318884 |
| D101, D102 | SS14 (+5V et VBUS vers 5V_MCU) | C2480 |
| R107, R108 | 10 kΩ (EN, IO0) | C25804 |
| R106, R105 | 5,1 kΩ (CC1, CC2) | C23186 |
| C103 | 1 µF (EN) | C5673 |
| C102 | 100 nF | C14663 |
| C101, C104, C105, C106 | 10 µF 0805 | C15850 |
| R114, R115 | 4,7 kΩ, pull-ups I2C vers +3V3 (inchangés) | C23162 |

---

## Bloc 1 — Entrée capteur v3 (×6)

Référence voie 1 (voies 2 à 6 identiques, chiffre des dizaines = n° de voie). Signal attendu : continu 0–3,3 V, ≈ 0 V au repos.

| Net | Broches (voie 1) |
|---|---|
| SENSOR_1 | J11.4, J11.5, D13 (TVS), R12 (4,7 k → JP11 → +3V3), R17 (1 M → GND), R16.1 (2,2 k) |
| CLAMP | R16.2, D12.3 (BAT54S), C12 (100 pF → GND), U12.2 (CH0) |
| MCP6S91_OUT | U12.1, R15.1 (10 k) |
| HYST_NODE | R15.2, R18.1 (680 k), U11.3 (+) |
| TLV_OUT_1 | U11.6, R18.2, U101.4 |
| THR_1 → filtre | THR_1 (DAC) → R13 (1 k) → C11 (100 nF → GND) → U11.2 (−) |
| V_SENS | J11.1, J11.2, F11 (PTC 200 mA, depuis +5V), C13 (10 µF) |
| ID (connecteur) | J11.7, J11.8, R14 (10 k → +3V3), D11 (TVS → GND), R11.1 |
| ID_ADC_1 | R11.2 (1 k), U114.1 (ADS7828) |
| CS_1 | U12.5, U111.21 |
| SPI_MOSI / SPI_SCK (communs) | U12.6 / U12.7 |
| +3V3 | U11.7, U12.8, D12 (K), JP11, R14, découplages C14-C17 |
| GND | U11.4, U11.8 (SHDN), U12.3 (VREF du PGA), U12.4, D12 (A), D11, D13, R17, J11.3/.6/.9/.10 |
| non connectées | U11.1, U11.5 |

| Réf (voie 1) | Valeur / pièce | Boîtier | LCSC |
|---|---|---|---|
| U11 | TLV3501AID | SOIC-8 | C43484 |
| U12 | MCP6S91 | MSOP-8 | C627647 |
| D12 | BAT54S | SOT-23 | C545549 |
| D11, D13 | PESD5V0S1BB (TVS 5 V bidir.) | SOD-523 | C97640 |
| R11, R13 | 1 kΩ | 0603 | C21190 |
| R12 | 4,7 kΩ | 0603 | C23162 |
| R14, R15 | 10 kΩ | 0603 | C25804 |
| R16 | 2,2 kΩ | 0603 | C4190 |
| R17 | 1 MΩ | 0603 | C22935 |
| R18 | 680 kΩ | 0603 | C25822 |
| C11, C14, C15 | 100 nF | 0603 | C14663 |
| C12 | 100 pF C0G | 0603 | C71664 |
| C13 | 10 µF 25 V | 0805 | C15850 |
| C16, C17 | 1 µF | 0603 | C5673 |
| F11 | PTC 200 mA | 1206 | C20984 |
| JP11 | 0 Ω (monté = tirage actif) | 0603 | C21189 |
| J11 | RJ45 HanXia HX-RJ45 90 5631-1x1 (10 br.) | THT | C25168869 |

---

## Bloc 2 — Sorties isolées flash / appareil photo

Chaîne par sortie : `*_CMD` (ESP32) → 180 Ω → LED de l'opto HCPL-063L → sortie opto (pull-up 10 k VISO_3V3) → inverseur 74LVC2G04 → grille 2N7002 (pull-down 100 k) → drain sur le RJ45. Logique directe : CMD haut = sortie active ; CMD bas ou haute impédance (démarrage, plantage) = sortie bloquée.

| Sortie | Commande | Opto | Pull-up | Inverseur | Pull-down | MOSFET | TVS | Connecteur |
|---|---|---|---|---|---|---|---|---|
| FOCUS | FOCUS_CMD (MCP23017 GPA6) → R73 | U71 (1→7) | R71 | U72 (1A→1Y) | R72 | Q71 | D71 | J71.3 |
| SHUTTER | SHUTTER_CMD (GPIO42) → R74 | U71 (4→6) | R76 | U72 (2A→2Y) | R75 | Q72 | D72 | J71.4 |
| FLASH_1 | FLASH_1_CMD → R83 | U81 (1→7) | R81 | U82 (1A→1Y) | R82 | Q81 | D81 | J81.4 |
| FLASH_2 | FLASH_2_CMD → R84 | U81 (4→6) | R86 | U82 (2A→2Y) | R85 | Q82 | D82 | J82.4 |
| FLASH_3 | FLASH_3_CMD → R89 | U83 (1→7) | R87 | U84 (1A→1Y) | R88 | Q83 | D83 | J83.4 |
| FLASH_4 | FLASH_4_CMD → R90 | U83 (4→6) | R92 | U84 (2A→2Y) | R91 | Q84 | D84 | J84.4 |

Brochages : HCPL-063L SO-8 : 1 A1, 2 K1, 3 K2, 4 A2, 5 GND sortie, 6 VO2, 7 VO1, 8 VCC. 74LVC2G04 SOT-23-6 : 1 1A, 2 GND, 3 2A, 4 2Y, 5 VCC, 6 1Y.

| Net | Broches |
|---|---|
| GND (côté ESP32) | U71.2, U71.3, U81.2, U81.3, U83.2, U83.3 |
| VISO_3V3 | U71.8, U81.8, U83.8, U72.5, U82.5, U84.5, R71, R76, R81, R86, R87, R92, C71-C72, C81-C84 (.1), U118 (Bloc 5b) |
| VISO_GND | U71.5, U81.5, U83.5, U72.2, U82.2, U84.2, sources Q71-Q84, R72/R75/R82/R85/R88/R91, anodes D71-D84, J71.5, J71.6, J81.5 … J84.5, U117.3, U118.1 |

**Règles** : aucun composant entre GND et VISO_GND ; TVS cathode côté sortie, anode VISO_GND ; RJ45 de sortie : broches 1-2, 7-10 (et 3, 6 sur les flashs) non connectées, blindage non connecté.

| Réf | Pièce | Qté | LCSC |
|---|---|---|---|
| U71, U81, U83 | Broadcom HCPL-063L-500E (2 voies, 3,3 V, SO-8) | 3 | C188704 |
| U72, U82, U84 | TI SN74LVC2G04DBVR (SOT-23-6) | 3 | C10428 |
| Q71, Q72, Q81-Q84 | 2N7002 (SOT-23) | 6 | C8545 |
| R73, R74, R83, R84, R89, R90 | 180 Ω 0603 | 6 | C22828 |
| R71, R76, R81, R86, R87, R92 | 10 kΩ 0603 | 6 | C25804 |
| R72, R75, R82, R85, R88, R91 | 100 kΩ 0603 | 6 | C25803 |
| C71, C72, C81-C84 | 100 nF 0603 (VISO_3V3 / VISO_GND) | 6 | C14663 |
| D71, D72, D81-D84 | SMF24A (TVS 24 V, SOD-123FL) | 6 | C169430 |
| J71, J81-J84 | RJ45 HanXia 10 broches | 5 | C25168869 |

---

## Bloc 3 — Électrovannes (×6)

| Net (canal n) | Broches |
|---|---|
| GPIO_VALVE_n | résistance de grille 220 Ω (R93, R94, R95, R99, R100, R101) |
| GATE_n | Q9n.1, résistance 220 Ω, pull-down 10 kΩ (R96, R97, R98, R102, R103, R104) → GND |
| VALVE_SW_n | Q9n.3 (drain), D9n.2 (anode SS14), CN9n.2 (−) |
| VALVE_PWR_n | D9n.1 (cathode), F9n.2, CN9n.1 (+) |
| +12V | F91.1 … F96.1 |
| GND | Q9n.2 (source), pull-downs |

| Réf | Pièce | LCSC |
|---|---|---|
| Q91-Q96 | AO3400A (SOT-23) | C20917 |
| D91-D96 | SS14 (SMA) | C2480 |
| F91-F96 | Bourns MF-MSMF110/24X-2 (1,1 A / 24 V, 1812) | C210835 |
| 220 Ω ×6 | 0603 | C22962 |
| 10 kΩ ×6 | 0603 | C25804 |
| CN91-CN96 | connecteur 2 points HX25003-2A (pas 2,5 mm) | — |

Une sortie vanne libre peut piloter une charge 12 V DC (ruban LED, ventilateur, pompe, module relais 12 V) : 12 V, 1,1 A max, PWM possible, non isolée. **Lumière dimmable** : déclarer la sortie en mode « lumière » dans le firmware (LEDC ≈ 20 kHz ; 8 voies LEDC : 6 vannes 5 kHz + servo 50 Hz + lumière). Aucun matériel supplémentaire (câble adaptateur HX25003 : broche 1 = +12V, broche 2 = −).

---

## Bloc 4 — Moteur pas à pas : supprimé (04/10)

Usage jugé trop rare pour le coût (module Pololu, GX12 4 broches, 1,5 A sur le 12 V, firmware de rampes). GPIO13 réaffecté au servo (Bloc 12), DIR / STEP_EN du MCP23017 libérés. Une rotation continue se fera avec un contrôleur externe piloté par une sortie.

---

## Bloc 5 — Alimentation (validé)

Bloc secteur **12 V, 5 A minimum**.

| Net | Broches |
|---|---|
| VIN_RAW | J112.1, F112.1 |
| VIN_F | F112.2, Q112.5-8 (drain) |
| +12V | Q112.1-3 (source), R116, D112 (cathode), C117 (470 µF), 2 × 10 µF, 100 nF, U115.1 (VIN), F91-F96, U131.1 (servo), bobine K131 (relais) |
| Q112_G | Q112.4, R116 (→ +12V), R117 (→ GND) : VGS ≈ −6 V |
| BUCK_SW | U115.2, L112.1, D113 (cathode) |
| +5V | L112.2, U115.4 (FB), C122 (330 µF), 100 nF, U116.3, 10 µF, D101, F11-F61, U117.2 |
| +3V3 | U116.2 + languette (4), C116 (10 µF) |
| GND | J112.2, R117, D112, D113 (anode), U115.3, U115.5 (ON/OFF), U115.6 (languette), U116.1, condensateurs |

| Réf | Pièce | LCSC |
|---|---|---|
| J112 | bornier KF128-5.08-2P | C474952 |
| F112 | fusible 6,3 A temporisé TLC TA3VT6.3 (2410) | C3014144 |
| Q112 | AO4407A (P-MOS 30 V 12 A, SOIC-8) | C16072 |
| R116, R117 | 10 kΩ 0603 | C25804 |
| D112 | SMBJ15A (TVS 600 W) | C83846 |
| C117 | 470 µF 25 V DMBJ RVT1E471M1010 | C970707 |
| 2 × 10 µF entrée, 10 µF AMS1117 entrée/sortie | 10 µF 25 V 0805 | C15850 |
| 100 nF ×2 | 0603 | C14663 |
| U115 | LM2596S-5.0 (UMW, TO-263-5) | C347421 |
| D113 | SS54 | C22452 |
| L112 | 33 µH 4,25 A SMDRI129-330MT | C2924828 |
| C122 | 330 µF 25 V low-ESR Panasonic EEE-FK1E331P (**pas de polymère** : instabilité du LM2596) | C178543 (alt. C970701) |
| U116 | AMS1117-3.3 | C6186 |

PCB : boucle C117-U115-D113 courte ; cuivre + vias sous la languette de U115 (~3 W) ; pistes 12 V ≥ 2 mm.

---

## Bloc 5b — Alimentation isolée (validé)

B0505S-1WR3 (5 V → 5 V isolé, non régulé, charge mini 20 mA) puis AMS1117-3.3 côté isolé (HCPL-063L : 2,7–3,6 V).

| Net | Broches |
|---|---|
| +5V / GND | U117.2 (VIN) / U117.1, condensateur d'entrée 10 µF |
| VISO_5V | U117.4 (+VO), C125 (10 µF), R118, U118.3 (VIN) |
| PRELOAD | R118 – R119 (2 × 220 Ω ≈ 11 mA) |
| VISO_3V3 | U118.2 + U118.4 (languette), C126 (10 µF) |
| VISO_GND | U117.3 (0V), C125, R119, U118.1, C126 |

| Réf | Pièce | LCSC |
|---|---|---|
| U117 | B0505S-1WR3 (SIP-4 : 1 GND, 2 VIN, 3 0V, 4 +VO) | C7465178 (EVISUN, alt. HI-LINK C5183119 ; Mornsun C131038 indisponible) |
| U118 | AMS1117-3.3 | C6186 |
| 3 × 10 µF | 0805 25 V | C15850 |
| R118, R119 | 220 Ω 0603 | C22962 |

PCB : bande sans cuivre (~2 mm) sous U117 entre les broches 1-2 et 3-4 ; plan VISO_GND séparé pour tout le côté isolé.

---

## Bloc 6 — Relais ×3 : supprimé

Remplacé par des **prises Wi-Fi** sur le réseau créé par l'ESP32 (éclairage, petit compresseur…), par les sorties vannes libres (charges 12 V DC, lumière dimmable, module relais 12 V externe) et par **une sortie relais embarquée** (Bloc 13). Voir [docs/sorties-wifi.md](docs/sorties-wifi.md).

---

## Bloc 7 — PWM lumière / servo : supprimé (04/10)

La lumière 12 V dimmable passe par une sortie vanne (même étage AO3400A + diode + PTC 1,1 A) ; le servo a sa sortie dédiée (Bloc 12). Plus de cavaliers de mode ni de risque de 12 V sur le servo. GPIO14 libre, un RJ45 de moins.

---

## Bloc 8 — Bus I2C (validé)

| Composant | Adresse | Rôle |
|---|---|---|
| U111 MCP23017 (SSOP-28) | 0x20 (A0-A2 à GND) | GPA0-5 = CS_1-6, GPA6 = FOCUS_CMD, **GPB2 = RELAY_CMD** (Bloc 13), **GPB3 = SERVO_OFF** (Bloc 12), GPB5 = LED de statut (R111 1 kΩ → CN111), RESET via R113 (10 k → +3V3) ; GPA7, GPB0-1, GPB4, GPB6-7 libres |
| U112 MCP4728 | 0x60 | LDAC à GND ; VOUTA-D (6-9) = THR_1-4 |
| U113 MCP4728 | 0x61 (reprogrammée au 1er démarrage) | LDAC = DAC2_LDAC (GPIO10 en v2, GPIO18 en v1) + R112 10 k → GND ; VOUTA/B = THR_5/6 |
| U114 ADS7828 (TSSOP-16) | 0x48 (A0, A1 à GND) | CH0-5 = ID_ADC_1-6, CH6-7 et COM à GND, REF : C115 1 µF (référence interne 2,5 V) |

MCP4728 MSOP-10 : 1 VDD, 2 SCL, 3 SDA, 4 LDAC, 5 RDY, 6-9 VOUTA-D, 10 VSS (attention : symbole EasyEDA numéroté en miroir côté droit). Découplage C111-C114 (100 nF).

| Réf | Pièce | LCSC |
|---|---|---|
| U111 | MCP23017-E/SS | C506653 |
| U112, U113 | MCP4728-E/UN | C108207 |
| U114 | ADS7828E/250 | C701648 |
| R111 | 1 kΩ | C21190 |
| R112, R113 | 10 kΩ | C25804 |
| C111-C114 | 100 nF | C14663 |
| C115 | 1 µF | C5673 |
| CN111 | connecteur 2 points (LED de statut déportée, anode broche 1) | — |

---

## Bloc 9 — Module capteur universel (carte déportée)

Un seul PCB, 8 variantes par options de montage ; code ID = résistance R1. Schéma KiCad : `kicad/module_capteur/`.

| Code | R1 | Variante | Montage spécifique |
|---|---|---|---|
| 1 | 0 Ω | Contact sec | CN1, R14 1 k, R15 2,2 k, C11, JP5 |
| 2 | 220 Ω | Laser | D1 BPW34, U1, R5/R6/C4 (VBIAS), JP1, R7 = 10 k, C6 = 10 pF, JP3 |
| 3 | 510 Ω | Barrière IR (récepteur) | idem laser, R7 = 100 k |
| 4 | 910 Ω | Lumière ambiante | idem laser, R7 = 1 M |
| 5 | 1,5 kΩ | Son (micro électret) | M1, R105, C8, R9, VMID, JP2, U1 (gain 101), enveloppe U1B/D3/C101/R13, JP4 |
| 6 | 2,2 kΩ | Piézo | idem son avec CN2, R11, D2 (gain 11) |
| 7 | 3 kΩ | Mouvement PIR | module AM312 sur H1, R16 = 0 Ω, R15, C11, JP5 |
| 8 | 4,3 kΩ | Émetteur IR | D4 IR333C + R17 100 Ω (pas de sortie) |
| 9-12 | 6,2 k … 18 kΩ | réserve | — |

Pièces principales : TLV9062IDR C398355, BPW34 C85128, micro GMI6027P C529943, IR333C-A C5130, BAT54S C545549, RJ45 C25168869.

---

## Bloc 10 — Protection ESD (validé)

| Lignes | Protection |
|---|---|
| SENSOR (×6) | PESD5V0S1BB + 2,2 kΩ + BAT54S (Bloc 1) |
| ID (×6) | PESD5V0S1BB (D11 … D61) + 1 kΩ série vers l'ADC (R11 … R61) |
| V_SENS | PTC + 10 µF (absorbe une décharge 8 kV / 150 pF) |
| FOCUS, SHUTTER, FLASH_1-4 | SMF24A vers VISO_GND (D71, D72, D81-D84) |
| SERVO_SIG | PESD5V0S1BB D132 (Bloc 12) + 220 Ω série |
| Vannes | diodes de roue libre SS14 / diode interne de l'AO3400A |
| Relais | contacts isolés de la bobine (aucune protection nécessaire) |
| Entrée 12 V | SMBJ15A (Bloc 5) |

Pas de condensateur entre VISO_GND et GND (isolation conservée).

---

## Bloc 12 — Sortie servo, rail 6 V dédié (validé, page 12)

LM2596S-ADJ alimenté par le +12V : V_SERVO = 1,23 V × (1 + R133 / R132) = 1,23 × (1 + 3,9 k / 1 k) ≈ **6,0 V, 3 A** (limitation interne, pas de PTC). Rail coupable par le MCP23017 : servo **hors tension au démarrage** tant que le firmware n'a pas fixé sa position. Repères = export EasyEDA du 05/10 (les feuilles KiCad de `kicad/sortie_servo/` utilisent une numérotation antérieure).

| Net | Broches |
|---|---|
| +12V | U131.1 (VIN), C131, C132 (10 µF), C133 (100 nF) |
| SERVO_SW | U131.2, L131.1, D131 (cathode, SS54) |
| V_SERVO | L131.2, R133 (3,9 kΩ), C134+ (330 µF), C135 (100 nF), C136+ (470 µF), J131.2 |
| SERVO_FB | U131.4, R133, R132 (1 kΩ → GND) |
| SERVO_OFF | U131.5 (ON/OFF), R131 (10 kΩ → +3V3), U111.4 (GPB3) — haut / haute impédance = coupé |
| SERVO_PWM | U101.19 (GPIO13, LEDC 50 Hz), R134 (10 kΩ → GND), U132.2 (A) |
| (sans nom) | U132.4 (Y), R135 (220 Ω) |
| (sans nom) | R135, D133 (TVS), J131.3 (signal) |
| +5V | U132.5 (VCC), C123 (100 nF) |
| GND | U131.3, U131 languette, R132, D131 anode, C131-C123, U132.1 (OE), U132.3, R134, D133, J131.1 |

J131 : bornier 3 points — 1 = GND, 2 = V_SERVO (6 V), 3 = signal (rallonge servo à câbler).

| Réf | Pièce | LCSC |
|---|---|---|
| U131 | LM2596S-ADJ (UMW, TO-263-5) | C347423 |
| L131 | 33 µH 4,25 A SMDRI129-330MT | C2924828 |
| D131 | SS54 | C22452 |
| C134 | 330 µF 25 V low-ESR Panasonic EEE-FK1E331P (pas de polymère) | C178543 (alt. C970701) |
| C136 | 470 µF 25 V DMBJ RVT1E471M1010 | C970707 |
| C131, C132 | 10 µF 25 V 0805 | C15850 |
| C133, C135, C123 | 100 nF 0603 | C14663 |
| R132 | 1 kΩ 1 % | C21190 |
| R133 | 3,9 kΩ 1 % UNI-ROYAL 0603WAF3901T5E | C23018 (rupture constatée le 05/10 ; secours : R133 = 39 kΩ C23153 + R132 = 10 kΩ C25804, même rapport, R132/R133 collées à U131.4) |
| R131, R134 | 10 kΩ | C25804 |
| R135 | 220 Ω | C22962 |
| U132 | SN74AHCT1G125DBVR (1 OE, 2 A, 3 GND, 4 Y, 5 VCC) | C7484 |
| D133 | PESD5V0S1BB | C97640 |
| J131 | bornier KEFA KF128-5.08-3P-AA | C474953 |

---

## Bloc 13 — Sortie relais, contact sec (validé, page 12)

| Net | Broches |
|---|---|
| RELAY_CMD | U111.3 (GPB2), R136 (220 Ω) |
| (grille) | R136, Q131.1, R137 (100 kΩ → GND, relais ouvert au démarrage) |
| (bobine −) | Q131.3 (drain), RELAY131.2, D132 anode |
| +12V | RELAY131.1 (bobine +), D132 cathode (SS14, roue libre) |
| GND | Q131.2 (source), R137 |
| RELAY_COM | RELAY131.5 (contact mobile), J132.1 |
| RELAY_NO | RELAY131.4, J132.2 |
| RELAY_NC | RELAY131.3, J132.3 |

Brochage COM / NO / NC vérifié sur le symbole LCSC de la C3633 (lame au repos sur le contact NC).

| Réf | Pièce | LCSC |
|---|---|---|
| RELAY131 | HONGFA HF32F/012-ZS3 (bobine 12 V, 1RT, 3 A) | C3633 |
| Q131 | AO3400A | C20917 |
| D132 | SS14 | C2480 |
| R136 | 220 Ω | C22962 |
| R137 | 100 kΩ | C25803 |
| J132 | bornier KEFA KF128-5.08-3P-AA | C474953 |

Contact 3 A / 30 V DC — **basse tension uniquement, jamais de 230 V** (sérigraphie près de J132).

---

## Bilan 12 V (sans moteur)

Vannes 3 A + servo ≈ 1,8 A (à pleine charge, sous 6 V) + +5V ≈ 1,5 A + relais 30 mA : bloc secteur **12 V 5 A** suffisant, 6 A pour la marge si vannes et servo forcent ensemble.

---

## Implantation PCB

Carte 175 × 125 mm, 4 couches (GND plein en couche 2, alimentations en couche 3). Placement v4 des 287 composants, règles et zones : [pcb/README.md](pcb/README.md) ; checklist : [docs/pcb-checklist.md](docs/pcb-checklist.md).

---

## Sorties Wi-Fi (remplacent le Bloc 6)

Prises connectées commandées par l'ESP32 sur **son propre réseau Wi-Fi** (point d'accès SoftAP, DHCP intégré : fonctionne sans box, partout), en HTTP / MQTT local : éclairage, petit compresseur (prise ≥ 10 A), ventilateur… Non critiques (50–500 ms), envoyées avant ou après une séquence de déclenchement. Détails : [docs/sorties-wifi.md](docs/sorties-wifi.md).

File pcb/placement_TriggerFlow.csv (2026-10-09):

Ref | Valeur | Empreinte | X_mm | Y_mm | Rotation | Face | Bloc
C11 | 100nF | C0603 | 22,00 | 88,20 | 0 | Dessus | Entrées capteur
C12 | 100pF | C0603 | 22,00 | 92,40 | 90 | Dessus | Entrées capteur
C13 | 10uF | C0805 | 14,60 | 101,20 | 0 | Dessus | Entrées capteur
C14 | 100nF | C0603 | 22,00 | 84,20 | 0 | Dessus | Entrées capteur
C15 | 100nF | C0603 | 24,40 | 92,40 | 90 | Dessus | Entrées capteur
C16 | 1uF | C0603 | 22,00 | 86,20 | 0 | Dessus | Entrées capteur
C17 | 1uF | C0603 | 9,10 | 92,40 | 90 | Dessus | Entrées capteur
C21 | 100nF | C0603 | 40,00 | 88,20 | 0 | Dessus | Entrées capteur
C22 | 100pF | C0603 | 40,00 | 92,40 | 90 | Dessus | Entrées capteur
C23 | 10uF | C0805 | 32,60 | 101,20 | 0 | Dessus | Entrées capteur
C24 | 100nF | C0603 | 40,00 | 84,20 | 0 | Dessus | Entrées capteur
C25 | 100nF | C0603 | 42,40 | 92,40 | 90 | Dessus | Entrées capteur
C26 | 1uF | C0603 | 40,00 | 86,20 | 0 | Dessus | Entrées capteur
C27 | 1uF | C0603 | 27,10 | 92,40 | 90 | Dessus | Entrées capteur
C31 | 100nF | C0603 | 58,00 | 88,20 | 0 | Dessus | Entrées capteur
C32 | 100pF | C0603 | 58,00 | 92,40 | 90 | Dessus | Entrées capteur
C33 | 10uF | C0805 | 50,60 | 101,20 | 0 | Dessus | Entrées capteur
C34 | 100nF | C0603 | 58,00 | 84,20 | 0 | Dessus | Entrées capteur
C35 | 100nF | C0603 | 60,40 | 92,40 | 90 | Dessus | Entrées capteur
C36 | 1uF | C0603 | 58,00 | 86,20 | 0 | Dessus | Entrées capteur
C37 | 1uF | C0603 | 45,10 | 92,40 | 90 | Dessus | Entrées capteur
C41 | 100nF | C0603 | 84,00 | 88,20 | 0 | Dessus | Entrées capteur
C42 | 100pF | C0603 | 84,00 | 92,40 | 90 | Dessus | Entrées capteur
C43 | 10uF | C0805 | 76,60 | 101,20 | 0 | Dessus | Entrées capteur
C44 | 100nF | C0603 | 84,00 | 84,20 | 0 | Dessus | Entrées capteur
C45 | 100nF | C0603 | 86,40 | 92,40 | 90 | Dessus | Entrées capteur
C46 | 1uF | C0603 | 84,00 | 86,20 | 0 | Dessus | Entrées capteur
C47 | 1uF | C0603 | 71,10 | 92,40 | 90 | Dessus | Entrées capteur
C51 | 100nF | C0603 | 102,00 | 88,20 | 0 | Dessus | Entrées capteur
C52 | 100pF | C0603 | 102,00 | 92,40 | 90 | Dessus | Entrées capteur
C53 | 10uF | C0805 | 94,60 | 101,20 | 0 | Dessus | Entrées capteur
C54 | 100nF | C0603 | 102,00 | 84,20 | 0 | Dessus | Entrées capteur
C55 | 100nF | C0603 | 104,40 | 92,40 | 90 | Dessus | Entrées capteur
C56 | 1uF | C0603 | 102,00 | 86,20 | 0 | Dessus | Entrées capteur
C57 | 1uF | C0603 | 89,10 | 92,40 | 90 | Dessus | Entrées capteur
C61 | 100nF | C0603 | 120,00 | 88,20 | 0 | Dessus | Entrées capteur
C62 | 100pF | C0603 | 120,00 | 92,40 | 90 | Dessus | Entrées capteur
C63 | 10uF | C0805 | 112,60 | 101,20 | 0 | Dessus | Entrées capteur
C64 | 100nF | C0603 | 120,00 | 84,20 | 0 | Dessus | Entrées capteur
C65 | 100nF | C0603 | 122,40 | 92,40 | 90 | Dessus | Entrées capteur
C66 | 1uF | C0603 | 120,00 | 86,20 | 0 | Dessus | Entrées capteur
C67 | 1uF | C0603 | 107,10 | 92,40 | 90 | Dessus | Entrées capteur
C71 | 100nF | C0603 | 17,00 | 35,00 | 0 | Dessus | Sorties isolées
C72 | 100nF | C0603 | 17,00 | 28,60 | 90 | Dessus | Sorties isolées
C81 | 100nF | C0603 | 44,00 | 35,00 | 0 | Dessus | Sorties isolées
C82 | 100nF | C0603 | 44,00 | 28,60 | 90 | Dessus | Sorties isolées
C83 | 100nF | C0603 | 80,00 | 35,00 | 0 | Dessus | Sorties isolées
C84 | 100nF | C0603 | 80,00 | 28,60 | 90 | Dessus | Sorties isolées
C101 | 10uF | C0805 | 9,20 | 65,70 | 90 | Dessus | ESP32 / 3V3
C102 | 100nF | C0603 | 11,30 | 65,50 | 90 | Dessus | ESP32 / 3V3
C103 | 1uF | C0603 | 15,30 | 65,50 | 90 | Dessus | ESP32 / 3V3
C104 | 10uF | C0805 | 46,00 | 49,00 | 90 | Dessus | ESP32 / 3V3
C105 | 10uF | C0805 | 48,40 | 49,00 | 90 | Dessus | ESP32 / 3V3
C106 | 10uF | C0805 | 35,50 | 51,50 | 90 | Dessus | ESP32 / 3V3
C111 | 100nF | C0603 | 106,50 | 55,00 | 90 | Dessus | Bus I2C
C112 | 100nF | C0603 | 95,00 | 69,50 | 0 | Dessus | Bus I2C
C113 | 100nF | C0603 | 104,00 | 69,50 | 0 | Dessus | Bus I2C
C114 | 100nF | C0603 | 117,00 | 70,30 | 0 | Dessus | Bus I2C
C115 | 1uF | C0603 | 121,80 | 66,00 | 90 | Dessus | Bus I2C
C116 | 10uF | C0805 | 149,80 | 120,50 | 90 | Dessus | ESP32 / 3V3
C117 | 470uF | CAP-SMD_BD10.0-L10.3-W10.3-LS11.3-FD | 152,00 | 96,80 | 0 | Dessus | Puissance
C118 | 10uF | C0805 | 155,50 | 105,00 | 0 | Dessus | Puissance
C119 | 10uF | C0805 | 155,50 | 107,30 | 0 | Dessus | Puissance
C120 | 100nF | C0603 | 155,50 | 109,50 | 0 | Dessus | Puissance
C121 | 10uF | C0805 | 137,60 | 120,50 | 90 | Dessus | ESP32 / 3V3
C122 | 330uF | CAP-SMD_BD8.0-L8.3-W8.3-FD | 130,00 | 109,00 | 0 | Dessus | Puissance
C123 | 100nF | C0603 | 116,00 | 18,60 | 0 | Dessus | Puissance
C124 | 10uF | C0805 | 95,50 | 44,50 | 0 | Dessus | Sorties isolées
C125 | 10uF | C0805 | 94,60 | 34,50 | 90 | Dessus | Sorties isolées
C126 | 10uF | C0805 | 67,50 | 33,00 | 90 | Dessus | Sorties isolées
C131 | 10uF | C0805 | 128,00 | 40,50 | 0 | Dessus | Puissance
C132 | 10uF | C0805 | 131,80 | 40,50 | 0 | Dessus | Puissance
C133 | 100nF | C0603 | 135,20 | 40,50 | 0 | Dessus | Puissance
C134 | 330uF | CAP-SMD_BD8.0-L8.3-W8.3-FD | 123,00 | 18,50 | 0 | Dessus | Puissance
C135 | 100nF | C0603 | 131,00 | 16,50 | 0 | Dessus | Puissance
C136 | 470uF | CAP-SMD_BD10.0-L10.3-W10.3-LS11.3-FD | 130,50 | 7,00 | 0 | Dessus | Puissance
C137 | 100nF | C0603 | 130,00 | 115,30 | 90 | Dessus | Puissance
CN91 | '' | CONN-TH_2P-P2.50_HX25003-2A | 134,00 | 47,75 | 0 | Dessus | Puissance
CN92 | '' | CONN-TH_2P-P2.50_HX25003-2A | 150,00 | 47,75 | 0 | Dessus | Puissance
CN93 | '' | CONN-TH_2P-P2.50_HX25003-2A | 166,00 | 47,75 | 0 | Dessus | Puissance
CN94 | '' | CONN-TH_2P-P2.50_HX25003-2A | 134,00 | 82,75 | 180 | Dessus | Puissance
CN95 | '' | CONN-TH_2P-P2.50_HX25003-2A | 150,00 | 82,75 | 180 | Dessus | Puissance
CN96 | '' | CONN-TH_2P-P2.50_HX25003-2A | 166,00 | 82,75 | 180 | Dessus | Puissance
CN111 | '' | HDR-TH_2P-P2.54-V-M-1 | 157,50 | 121,75 | 0 | Dessus | ESP32 / 3V3
D11 | '' | SOD-523_L1.2-W0.8-LS1.6-BI | 20,60 | 101,20 | 0 | Dessus | Entrées capteur
D12 | '' | SOT-23-3_L2.9-W1.3-P1.90-LS2.4-TL | 19,00 | 92,40 | 0 | Dessus | Entrées capteur
D13 | '' | SOD-523_L1.2-W0.8-LS1.6-BI | 17,90 | 101,20 | 0 | Dessus | Entrées capteur
D21 | '' | SOD-523_L1.2-W0.8-LS1.6-BI | 38,60 | 101,20 | 0 | Dessus | Entrées capteur
D22 | '' | SOT-23-3_L2.9-W1.3-P1.90-LS2.4-TL | 37,00 | 92,40 | 0 | Dessus | Entrées capteur
D23 | '' | SOD-523_L1.2-W0.8-LS1.6-BI | 35,90 | 101,20 | 0 | Dessus | Entrées capteur
D31 | '' | SOD-523_L1.2-W0.8-LS1.6-BI | 56,60 | 101,20 | 0 | Dessus | Entrées capteur
D32 | '' | SOT-23-3_L2.9-W1.3-P1.90-LS2.4-TL | 55,00 | 92,40 | 0 | Dessus | Entrées capteur
D33 | '' | SOD-523_L1.2-W0.8-LS1.6-BI | 53,90 | 101,20 | 0 | Dessus | Entrées capteur
D41 | '' | SOD-523_L1.2-W0.8-LS1.6-BI | 82,60 | 101,20 | 0 | Dessus | Entrées capteur
D42 | '' | SOT-23-3_L2.9-W1.3-P1.90-LS2.4-TL | 81,00 | 92,40 | 0 | Dessus | Entrées capteur
D43 | '' | SOD-523_L1.2-W0.8-LS1.6-BI | 79,90 | 101,20 | 0 | Dessus | Entrées capteur
D51 | '' | SOD-523_L1.2-W0.8-LS1.6-BI | 100,60 | 101,20 | 0 | Dessus | Entrées capteur
D52 | '' | SOT-23-3_L2.9-W1.3-P1.90-LS2.4-TL | 99,00 | 92,40 | 0 | Dessus | Entrées capteur
D53 | '' | SOD-523_L1.2-W0.8-LS1.6-BI | 97,90 | 101,20 | 0 | Dessus | Entrées capteur
D61 | '' | SOD-523_L1.2-W0.8-LS1.6-BI | 118,60 | 101,20 | 0 | Dessus | Entrées capteur
D62 | '' | SOT-23-3_L2.9-W1.3-P1.90-LS2.4-TL | 117,00 | 92,40 | 0 | Dessus | Entrées capteur
D63 | '' | SOD-523_L1.2-W0.8-LS1.6-BI | 115,90 | 101,20 | 0 | Dessus | Entrées capteur
D71 | '' | SOD-123F_L2.8-W1.8-LS3.7-RD | 13,00 | 28,80 | 0 | Dessus | Sorties isolées
D72 | '' | SOD-123F_L2.8-W1.8-LS3.7-RD | 21,00 | 28,80 | 0 | Dessus | Sorties isolées
D81 | '' | SOD-123F_L2.8-W1.8-LS3.7-RD | 35,00 | 28,50 | 0 | Dessus | Sorties isolées
D82 | '' | SOD-123F_L2.8-W1.8-LS3.7-RD | 53,00 | 28,50 | 0 | Dessus | Sorties isolées
D83 | '' | SOD-123F_L2.8-W1.8-LS3.7-RD | 71,00 | 28,50 | 0 | Dessus | Sorties isolées
D84 | '' | SOD-123F_L2.8-W1.8-LS3.7-RD | 89,00 | 28,50 | 0 | Dessus | Sorties isolées
D91 | '' | SMA_L4.3-W2.6-LS5.2-RD | 137,50 | 54,25 | 0 | Dessus | Puissance
D92 | '' | SMA_L4.3-W2.6-LS5.2-RD | 153,50 | 54,25 | 0 | Dessus | Puissance
D93 | '' | SMA_L4.3-W2.6-LS5.2-RD | 169,50 | 54,25 | 0 | Dessus | Puissance
D94 | '' | SMA_L4.3-W2.6-LS5.2-RD | 137,50 | 76,25 | 0 | Dessus | Puissance
D95 | '' | SMA_L4.3-W2.6-LS5.2-RD | 153,50 | 76,25 | 0 | Dessus | Puissance
D96 | '' | SMA_L4.3-W2.6-LS5.2-RD | 169,50 | 76,25 | 0 | Dessus | Puissance
D101 | SS14 | SMA_L4.2-W2.6-LS5.0-RD_1 | 31,00 | 47,20 | 0 | Dessus | ESP32 / 3V3
D102 | '' | SMA_L4.2-W2.6-LS5.0-RD_1 | 20,00 | 70,50 | 0 | Dessus | ESP32 / 3V3
D112 | '' | SMB_L4.6-W3.6-LS5.3-RD | 163,00 | 27,00 | 90 | Dessus | Puissance
D113 | '' | SMA_L4.4-W2.8-LS5.4-R-RD | 151,50 | 108,50 | 90 | Dessus | Puissance
D131 | SS54 | SMA_L4.4-W2.8-LS5.4-R-RD | 123,00 | 41,60 | 0 | Dessus | Puissance
D132 | SS14 | SMA_L4.2-W2.6-LS5.0-RD_1 | 154,50 | 24,00 | 90 | Dessus | Puissance
D133 | PESD5V0S1BB | SOD-523_L1.2-W0.8-LS1.6-BI | 108,50 | 15,00 | 90 | Dessus | Puissance
F11 | '' | F1206 | 10,60 | 101,20 | 0 | Dessus | Entrées capteur
F21 | '' | F1206 | 28,60 | 101,20 | 0 | Dessus | Entrées capteur
F31 | '' | F1206 | 46,60 | 101,20 | 0 | Dessus | Entrées capteur
F41 | '' | F1206 | 72,60 | 101,20 | 0 | Dessus | Entrées capteur
F51 | '' | F1206 | 90,60 | 101,20 | 0 | Dessus | Entrées capteur
F61 | '' | F1206 | 108,60 | 101,20 | 0 | Dessus | Entrées capteur
F91 | '' | F1812 | 137,50 | 60,75 | 0 | Dessus | Puissance
F92 | '' | F1812 | 153,50 | 60,75 | 0 | Dessus | Puissance
F93 | '' | F1812 | 169,50 | 60,75 | 0 | Dessus | Puissance
F94 | '' | F1812 | 137,50 | 69,75 | 0 | Dessus | Puissance
F95 | '' | F1812 | 153,50 | 69,75 | 0 | Dessus | Puissance
F96 | '' | F1812 | 169,50 | 69,75 | 0 | Dessus | Puissance
F112 | '' | F2410 | 171,50 | 16,50 | 90 | Dessus | Puissance
J11 | '' | RJ456-TH_HX-RJ45-90-5631-1X1-8P8C | 17,00 | 114,25 | 0 | Dessus | Entrées capteur
J21 | '' | RJ456-TH_HX-RJ45-90-5631-1X1-8P8C | 35,00 | 114,25 | 0 | Dessus | Entrées capteur
J31 | '' | RJ456-TH_HX-RJ45-90-5631-1X1-8P8C | 53,00 | 114,25 | 0 | Dessus | Entrées capteur
J41 | '' | RJ456-TH_HX-RJ45-90-5631-1X1-8P8C | 79,00 | 114,25 | 0 | Dessus | Entrées capteur
J51 | '' | RJ456-TH_HX-RJ45-90-5631-1X1-8P8C | 97,00 | 114,25 | 0 | Dessus | Entrées capteur
J61 | '' | RJ456-TH_HX-RJ45-90-5631-1X1-8P8C | 115,00 | 114,25 | 0 | Dessus | Entrées capteur
J71 | '' | RJ456-TH_HX-RJ45-90-5631-1X1-8P8C | 17,00 | 10,75 | 180 | Dessus | Sorties isolées
J81 | '' | RJ456-TH_HX-RJ45-90-5631-1X1-8P8C | 35,00 | 10,75 | 180 | Dessus | Sorties isolées
J82 | '' | RJ456-TH_HX-RJ45-90-5631-1X1-8P8C | 53,00 | 10,75 | 180 | Dessus | Sorties isolées
J83 | '' | RJ456-TH_HX-RJ45-90-5631-1X1-8P8C | 71,00 | 10,75 | 180 | Dessus | Sorties isolées
J84 | '' | RJ456-TH_HX-RJ45-90-5631-1X1-8P8C | 89,00 | 10,75 | 180 | Dessus | Sorties isolées
J101 | '' | USB-C_SMD-TYPE-C-31-M-12_1 | 4,40 | 75,00 | 90 | Dessus | ESP32 / 3V3
J112 | '' | CONN-TH_P5.08_KF128-5.08-2P | 162,00 | 4,50 | 0 | Dessus | Puissance
J131 | KF128-5.08-3P (servo) | CONN-TH_3P-P5.08_KF128-5.08-3P | 116,00 | 5,50 | 0 | Dessus | Puissance
J132 | KF128-5.08-3P (relais) | CONN-TH_3P-P5.08_KF128-5.08-3P | 147,00 | 5,50 | 0 | Dessus | Puissance
JP11 | '0Ω' | R0603 | 21,50 | 96,60 | 0 | Dessus | Entrées capteur
JP21 | '0Ω' | R0603 | 39,50 | 96,60 | 0 | Dessus | Entrées capteur
JP31 | '0Ω' | R0603 | 57,50 | 96,60 | 0 | Dessus | Entrées capteur
JP41 | '0Ω' | R0603 | 83,50 | 96,60 | 0 | Dessus | Entrées capteur
JP51 | '0Ω' | R0603 | 101,50 | 96,60 | 0 | Dessus | Entrées capteur
JP61 | '0Ω' | R0603 | 119,50 | 96,60 | 0 | Dessus | Entrées capteur
L112 | 33uH | IND-SMD_L12.5-W12.5 | 141,50 | 109,30 | 0 | Dessus | Puissance
L131 | 33uH | IND-SMD_L12.5-W12.5 | 129,50 | 31,00 | 0 | Dessus | Puissance
Q71 | '' | SOT-23-3_L2.9-W1.3-P1.90-LS2.4-BR | 13,00 | 25,00 | 0 | Dessus | Sorties isolées
Q72 | '' | SOT-23-3_L2.9-W1.3-P1.90-LS2.4-BR | 21,00 | 25,00 | 0 | Dessus | Sorties isolées
Q81 | '' | SOT-23-3_L2.9-W1.3-P1.90-LS2.4-BR | 35,00 | 25,00 | 0 | Dessus | Sorties isolées
Q82 | '' | SOT-23-3_L2.9-W1.3-P1.90-LS2.4-BR | 53,00 | 25,00 | 0 | Dessus | Sorties isolées
Q83 | '' | SOT-23-3_L2.9-W1.3-P1.90-LS2.4-BR | 71,00 | 25,00 | 0 | Dessus | Sorties isolées
Q84 | '' | SOT-23-3_L2.9-W1.3-P1.90-LS2.4-BR | 89,00 | 25,00 | 0 | Dessus | Sorties isolées
Q91 | '' | SOT-23_L2.9-W1.3-P1.90-LS2.4-BR | 130,00 | 54,25 | 0 | Dessus | Puissance
Q92 | '' | SOT-23_L2.9-W1.3-P1.90-LS2.4-BR | 146,00 | 54,25 | 0 | Dessus | Puissance
Q93 | '' | SOT-23_L2.9-W1.3-P1.90-LS2.4-BR | 162,00 | 54,25 | 0 | Dessus | Puissance
Q94 | '' | SOT-23_L2.9-W1.3-P1.90-LS2.4-BR | 130,00 | 76,25 | 0 | Dessus | Puissance
Q95 | '' | SOT-23_L2.9-W1.3-P1.90-LS2.4-BR | 146,00 | 76,25 | 0 | Dessus | Puissance
Q96 | '' | SOT-23_L2.9-W1.3-P1.90-LS2.4-BR | 162,00 | 76,25 | 0 | Dessus | Puissance
Q112 | '' | SOIC-8_L4.9-W3.9-P1.27-LS6.0-BL | 171,00 | 27,00 | 90 | Dessus | Puissance
Q131 | AO3400A | SOT-23-3_L2.9-W1.3-P1.90-LS2.4-BR | 139,50 | 22,00 | 0 | Dessus | Puissance
R11 | '1kΩ' | R0603 | 24,20 | 101,20 | 0 | Dessus | Entrées capteur
R12 | '4.7kΩ' | R0603 | 18,50 | 96,60 | 0 | Dessus | Entrées capteur
R13 | '1kΩ' | R0603 | 18,60 | 88,20 | 0 | Dessus | Entrées capteur
R14 | '10kΩ' | R0603 | 24,50 | 96,60 | 0 | Dessus | Entrées capteur
R15 | '10kΩ' | R0603 | 18,60 | 84,20 | 0 | Dessus | Entrées capteur
R16 | '2.2kΩ' | R0603 | 12,50 | 96,60 | 0 | Dessus | Entrées capteur
R17 | '1MΩ' | R0603 | 15,50 | 96,60 | 0 | Dessus | Entrées capteur
R18 | '680kΩ' | R0603 | 18,60 | 86,20 | 0 | Dessus | Entrées capteur
R21 | '1kΩ' | R0603 | 42,20 | 101,20 | 0 | Dessus | Entrées capteur
R22 | '4.7kΩ' | R0603 | 36,50 | 96,60 | 0 | Dessus | Entrées capteur
R23 | '1kΩ' | R0603 | 36,60 | 88,20 | 0 | Dessus | Entrées capteur
R24 | '10kΩ' | R0603 | 42,50 | 96,60 | 0 | Dessus | Entrées capteur
R25 | '10kΩ' | R0603 | 36,60 | 84,20 | 0 | Dessus | Entrées capteur
R26 | '2.2kΩ' | R0603 | 30,50 | 96,60 | 0 | Dessus | Entrées capteur
R27 | '1MΩ' | R0603 | 33,50 | 96,60 | 0 | Dessus | Entrées capteur
R28 | '680kΩ' | R0603 | 36,60 | 86,20 | 0 | Dessus | Entrées capteur
R31 | '1kΩ' | R0603 | 60,20 | 101,20 | 0 | Dessus | Entrées capteur
R32 | '4.7kΩ' | R0603 | 54,50 | 96,60 | 0 | Dessus | Entrées capteur
R33 | '1kΩ' | R0603 | 54,60 | 88,20 | 0 | Dessus | Entrées capteur
R34 | '10kΩ' | R0603 | 60,50 | 96,60 | 0 | Dessus | Entrées capteur
R35 | '10kΩ' | R0603 | 54,60 | 84,20 | 0 | Dessus | Entrées capteur
R36 | '2.2kΩ' | R0603 | 48,50 | 96,60 | 0 | Dessus | Entrées capteur
R37 | '1MΩ' | R0603 | 51,50 | 96,60 | 0 | Dessus | Entrées capteur
R38 | '680kΩ' | R0603 | 54,60 | 86,20 | 0 | Dessus | Entrées capteur
R41 | '1kΩ' | R0603 | 86,20 | 101,20 | 0 | Dessus | Entrées capteur
R42 | '4.7kΩ' | R0603 | 80,50 | 96,60 | 0 | Dessus | Entrées capteur
R43 | '1kΩ' | R0603 | 80,60 | 88,20 | 0 | Dessus | Entrées capteur
R44 | '10kΩ' | R0603 | 86,50 | 96,60 | 0 | Dessus | Entrées capteur
R45 | '10kΩ' | R0603 | 80,60 | 84,20 | 0 | Dessus | Entrées capteur
R46 | '2.2kΩ' | R0603 | 74,50 | 96,60 | 0 | Dessus | Entrées capteur
R47 | '1MΩ' | R0603 | 77,50 | 96,60 | 0 | Dessus | Entrées capteur
R48 | '680kΩ' | R0603 | 80,60 | 86,20 | 0 | Dessus | Entrées capteur
R51 | '1kΩ' | R0603 | 104,20 | 101,20 | 0 | Dessus | Entrées capteur
R52 | '4.7kΩ' | R0603 | 98,50 | 96,60 | 0 | Dessus | Entrées capteur
R53 | '1kΩ' | R0603 | 98,60 | 88,20 | 0 | Dessus | Entrées capteur
R54 | '10kΩ' | R0603 | 104,50 | 96,60 | 0 | Dessus | Entrées capteur
R55 | '10kΩ' | R0603 | 98,60 | 84,20 | 0 | Dessus | Entrées capteur
R56 | '2.2kΩ' | R0603 | 92,50 | 96,60 | 0 | Dessus | Entrées capteur
R57 | '1MΩ' | R0603 | 95,50 | 96,60 | 0 | Dessus | Entrées capteur
R58 | '680kΩ' | R0603 | 98,60 | 86,20 | 0 | Dessus | Entrées capteur
R61 | '1kΩ' | R0603 | 122,20 | 101,20 | 0 | Dessus | Entrées capteur
R62 | '4.7kΩ' | R0603 | 116,50 | 96,60 | 0 | Dessus | Entrées capteur
R63 | '1kΩ' | R0603 | 116,60 | 88,20 | 0 | Dessus | Entrées capteur
R64 | '10kΩ' | R0603 | 122,50 | 96,60 | 0 | Dessus | Entrées capteur
R65 | '10kΩ' | R0603 | 116,60 | 84,20 | 0 | Dessus | Entrées capteur
R66 | '2.2kΩ' | R0603 | 110,50 | 96,60 | 0 | Dessus | Entrées capteur
R67 | '1MΩ' | R0603 | 113,50 | 96,60 | 0 | Dessus | Entrées capteur
R68 | '680kΩ' | R0603 | 116,60 | 86,20 | 0 | Dessus | Entrées capteur
R71 | '10kΩ' | R0603 | 14,00 | 34,80 | 90 | Dessus | Sorties isolées
R72 | '100kΩ' | R0603 | 9,00 | 25,00 | 90 | Dessus | Sorties isolées
R73 | '180Ω' | R0603 | 12,60 | 42,60 | 0 | Dessus | Sorties isolées
R74 | '180Ω' | R0603 | 21,40 | 42,60 | 0 | Dessus | Sorties isolées
R75 | '100kΩ' | R0603 | 25,00 | 25,00 | 90 | Dessus | Sorties isolées
R76 | '10kΩ' | R0603 | 20,00 | 34,80 | 90 | Dessus | Sorties isolées
R81 | '10kΩ' | R0603 | 41,00 | 34,80 | 90 | Dessus | Sorties isolées
R82 | '100kΩ' | R0603 | 31,00 | 25,00 | 90 | Dessus | Sorties isolées
R83 | '180Ω' | R0603 | 39,60 | 42,60 | 0 | Dessus | Sorties isolées
R84 | '180Ω' | R0603 | 48,40 | 42,60 | 0 | Dessus | Sorties isolées
R85 | '100kΩ' | R0603 | 57,00 | 25,00 | 90 | Dessus | Sorties isolées
R86 | '10kΩ' | R0603 | 47,00 | 34,80 | 90 | Dessus | Sorties isolées
R87 | '10kΩ' | R0603 | 77,00 | 34,80 | 90 | Dessus | Sorties isolées
R88 | '100kΩ' | R0603 | 67,00 | 25,00 | 90 | Dessus | Sorties isolées
R89 | '180Ω' | R0603 | 75,60 | 42,60 | 0 | Dessus | Sorties isolées
R90 | '180Ω' | R0603 | 84,40 | 42,60 | 0 | Dessus | Sorties isolées
R91 | '100kΩ' | R0603 | 93,00 | 25,00 | 90 | Dessus | Sorties isolées
R92 | '10kΩ' | R0603 | 83,00 | 34,80 | 90 | Dessus | Sorties isolées
R93 | '220Ω' | R0603 | 128,50 | 58,75 | 0 | Dessus | Puissance
R94 | '220Ω' | R0603 | 144,50 | 58,75 | 0 | Dessus | Puissance
R95 | '220Ω' | R0603 | 160,50 | 58,75 | 0 | Dessus | Puissance
R96 | '10kΩ' | R0603 | 128,50 | 60,85 | 0 | Dessus | Puissance
R97 | '10kΩ' | R0603 | 144,50 | 60,85 | 0 | Dessus | Puissance
R98 | '10kΩ' | R0603 | 160,50 | 60,85 | 0 | Dessus | Puissance
R99 | '220Ω' | R0603 | 128,50 | 69,65 | 0 | Dessus | Puissance
R100 | '220Ω' | R0603 | 144,50 | 69,65 | 0 | Dessus | Puissance
R101 | '220Ω' | R0603 | 160,50 | 69,65 | 0 | Dessus | Puissance
R102 | '10kΩ' | R0603 | 128,50 | 71,75 | 0 | Dessus | Puissance
R103 | '10kΩ' | R0603 | 144,50 | 71,75 | 0 | Dessus | Puissance
R104 | '10kΩ' | R0603 | 160,50 | 71,75 | 0 | Dessus | Puissance
R105 | '5.1kΩ' | R0603 | 15,20 | 78,60 | 0 | Dessus | ESP32 / 3V3
R106 | '5.1kΩ' | R0603 | 12,00 | 78,60 | 0 | Dessus | ESP32 / 3V3
R107 | '10kΩ' | R0603 | 13,30 | 65,50 | 90 | Dessus | ESP32 / 3V3
R108 | '10kΩ' | R0603 | 28,50 | 52,00 | 90 | Dessus | ESP32 / 3V3
R111 | '1kΩ' | R0603 | 106,50 | 51,50 | 90 | Dessus | Bus I2C
R112 | '10kΩ' | R0603 | 108,40 | 66,00 | 90 | Dessus | Bus I2C
R113 | '10kΩ' | R0603 | 106,50 | 58,50 | 90 | Dessus | Bus I2C
R114 | '4.7kΩ' | R0603 | 96,00 | 50,00 | 0 | Dessus | Bus I2C
R115 | '4.7kΩ' | R0603 | 96,00 | 52,20 | 0 | Dessus | Bus I2C
R116 | '10kΩ' | R0603 | 163,00 | 16,50 | 0 | Dessus | Puissance
R117 | '10kΩ' | R0603 | 163,00 | 18,70 | 0 | Dessus | Puissance
R118 | '220Ω' | R0603 | 96,50 | 36,80 | 90 | Dessus | Sorties isolées
R119 | '220Ω' | R0603 | 98,00 | 31,00 | 90 | Dessus | Sorties isolées
R131 | '10kΩ' | R0603 | 107,00 | 42,20 | 0 | Dessus | Puissance
R132 | '1kΩ' | R0603 | 110,40 | 42,20 | 0 | Dessus | Puissance
R133 | '3.9kΩ' | R0603 | 113,80 | 42,20 | 0 | Dessus | Puissance
R134 | '10kΩ' | R0603 | 110,20 | 15,00 | 90 | Dessus | Puissance
R135 | '220Ω' | R0603 | 112,00 | 15,00 | 90 | Dessus | Puissance
R136 | '220Ω' | R0603 | 139,50 | 17,50 | 90 | Dessus | Puissance
R137 | '100kΩ' | R0603 | 139,50 | 26,50 | 90 | Dessus | Puissance
RELAY131 | HF32F/012-ZS3 | RELAY-TH_HF32F-012-ZS3 | 147,00 | 24,00 | 90 | Dessus | Puissance
SW101 | '' | SW-SMD_4P-L5.1-W5.1-P3.70-LS6.5-TL_H1.5 | 33,00 | 60,00 | 0 | Dessus | ESP32 / 3V3
SW102 | '' | SW-SMD_4P-L5.1-W5.1-P3.70-LS6.5-TL_H1.5 | 41,00 | 60,00 | 0 | Dessus | ESP32 / 3V3
U11 | '' | SOP-8_L4.9-W3.9-P1.27-LS6.0-BL | 13,50 | 86,00 | 0 | Dessus | Entrées capteur
U12 | '' | SOIC-8_L4.9-W3.9-P1.27-LS6.0-BL | 13,50 | 92,40 | 0 | Dessus | Entrées capteur
U21 | '' | SOP-8_L4.9-W3.9-P1.27-LS6.0-BL | 31,50 | 86,00 | 0 | Dessus | Entrées capteur
U22 | '' | SOIC-8_L4.9-W3.9-P1.27-LS6.0-BL | 31,50 | 92,40 | 0 | Dessus | Entrées capteur
U31 | '' | SOP-8_L4.9-W3.9-P1.27-LS6.0-BL | 49,50 | 86,00 | 0 | Dessus | Entrées capteur
U32 | '' | SOIC-8_L4.9-W3.9-P1.27-LS6.0-BL | 49,50 | 92,40 | 0 | Dessus | Entrées capteur
U41 | '' | SOP-8_L4.9-W3.9-P1.27-LS6.0-BL | 75,50 | 86,00 | 0 | Dessus | Entrées capteur
U42 | '' | SOIC-8_L4.9-W3.9-P1.27-LS6.0-BL | 75,50 | 92,40 | 0 | Dessus | Entrées capteur
U51 | '' | SOP-8_L4.9-W3.9-P1.27-LS6.0-BL | 93,50 | 86,00 | 0 | Dessus | Entrées capteur
U52 | '' | SOIC-8_L4.9-W3.9-P1.27-LS6.0-BL | 93,50 | 92,40 | 0 | Dessus | Entrées capteur
U61 | '' | SOP-8_L4.9-W3.9-P1.27-LS6.0-BL | 111,50 | 86,00 | 0 | Dessus | Entrées capteur
U62 | '' | SOIC-8_L4.9-W3.9-P1.27-LS6.0-BL | 111,50 | 92,40 | 0 | Dessus | Entrées capteur
U71 | '' | SO-8_L4.9-W3.9-P1.27-LS5.9-BL | 17,00 | 40,00 | 90 | Dessus | Sorties isolées
U72 | '' | SOT-23-6_L2.9-W1.6-P0.95-LS2.8-BR | 17,00 | 32,20 | 0 | Dessus | Sorties isolées
U81 | '' | SO-8_L4.9-W3.9-P1.27-LS5.9-BL | 44,00 | 40,00 | 90 | Dessus | Sorties isolées
U82 | '' | SOT-23-6_L2.9-W1.6-P0.95-LS2.8-BR | 44,00 | 32,20 | 0 | Dessus | Sorties isolées
U83 | '' | SO-8_L4.9-W3.9-P1.27-LS5.9-BL | 80,00 | 40,00 | 90 | Dessus | Sorties isolées
U84 | '' | SOT-23-6_L2.9-W1.6-P0.95-LS2.8-BR | 80,00 | 32,20 | 0 | Dessus | Sorties isolées
U101 | '2.4GHz' | WIRELM-SMD_ESP32-S3-WROOM-1 | 13,25 | 54,00 | 90 | Dessus | ESP32 / 3V3
U102 | '' | SOT-23-6_L2.9-W1.6-P0.95-LS2.8-BL | 12,00 | 74,80 | 0 | Dessus | ESP32 / 3V3
U103 | '' | HDR-TH_3P-P2.54-V-M-1 | 50,00 | 66,00 | 0 | Dessus | ESP32 / 3V3
U104 | '' | SOT-223-3_L6.5-W3.4-P2.30-LS7.0-BR | 40,50 | 50,00 | 0 | Dessus | ESP32 / 3V3
U111 | '' | SSOP-28_L10.2-W5.3-P0.65-LS7.8-BL | 113,00 | 54,00 | 0 | Dessus | Bus I2C
U112 | '' | MSOP-10_L3.0-W3.0-P0.50-LS5.0-TL | 95,00 | 66,00 | 0 | Dessus | Bus I2C
U113 | '' | MSOP-10_L3.0-W3.0-P0.50-LS5.0-TL | 104,00 | 66,00 | 0 | Dessus | Bus I2C
U114 | '' | TSSOP-16_L5.0-W4.4-P0.65-LS6.4-BL | 117,00 | 66,00 | 0 | Dessus | Bus I2C
U115 | '' | TO-263-5_L10.2-W8.9-P1.70-BR | 166,00 | 108,00 | 90 | Dessus | Puissance
U116 | '' | SOT-223-3_L6.5-W3.4-P2.30-LS7.0-BR | 144,00 | 120,50 | 0 | Dessus | ESP32 / 3V3
U117 | '200kHz~340kHz' | PWRM-TH_B0505S-1WR3 | 90,00 | 40,00 | 90 | Dessus | Sorties isolées
U118 | '' | SOT-223-3_L6.5-W3.4-P2.30-LS7.0-BR | 62,00 | 28,00 | 0 | Dessus | Sorties isolées
U131 | LM2596S-ADJ | TO-263-5_L10.2-W8.9-P1.70-BR | 113,00 | 34,00 | 90 | Dessus | Puissance
U132 | SN74AHCT1G125 | SOT-23-5_L3.0-W1.7-P0.95-LS2.8-BR | 116,00 | 15,00 | 0 | Dessus | Puissance
H1 | M3 NPTH | MountingHole_3.2mm | 4 | 4 | 0 | — | Mécanique
H5 | M3 NPTH | MountingHole_3.2mm | 101 | 6 | 0 | — | Mécanique
H2 | M3 GND | MountingHole_3.2mm | 171 | 4 | 0 | — | Mécanique
H3 | M3 GND | MountingHole_3.2mm | 4 | 121 | 0 | — | Mécanique
H4 | M3 GND | MountingHole_3.2mm | 171 | 121 | 0 | — | Mécanique
H6 | M3 GND | MountingHole_3.2mm | 66 | 121 | 0 | — | Mécanique

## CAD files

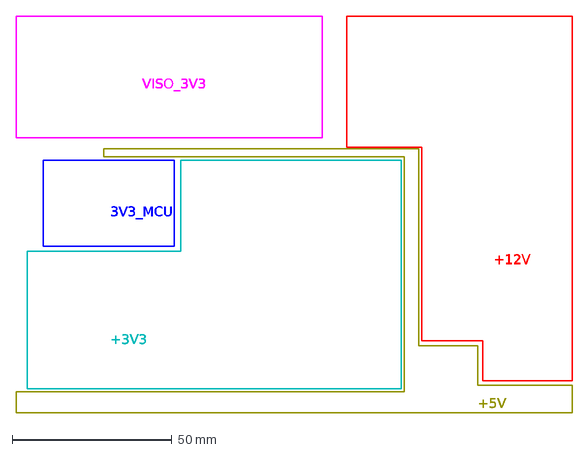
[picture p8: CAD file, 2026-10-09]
pcb/dxf/TriggerFlow_5_couche3_plages.dxf
VISO_3V3
+12V
+3V3
+5V
3V3_MCU

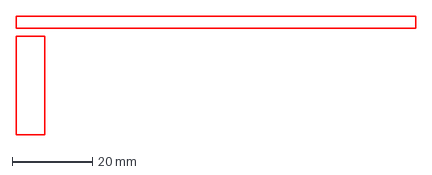
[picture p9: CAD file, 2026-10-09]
pcb/dxf/TriggerFlow_3_zones_interdites.dxf
99.4 x 29.5 mm

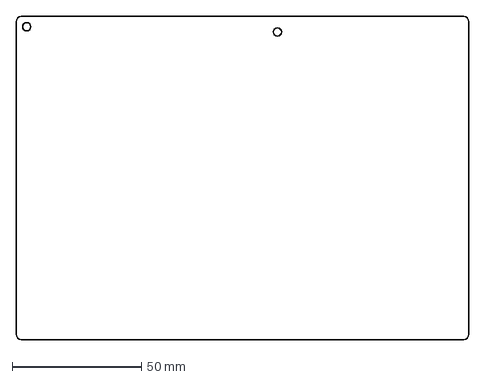
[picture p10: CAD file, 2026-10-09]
pcb/dxf/TriggerFlow_1_contour.dxf
175.0 x 125.0 mm

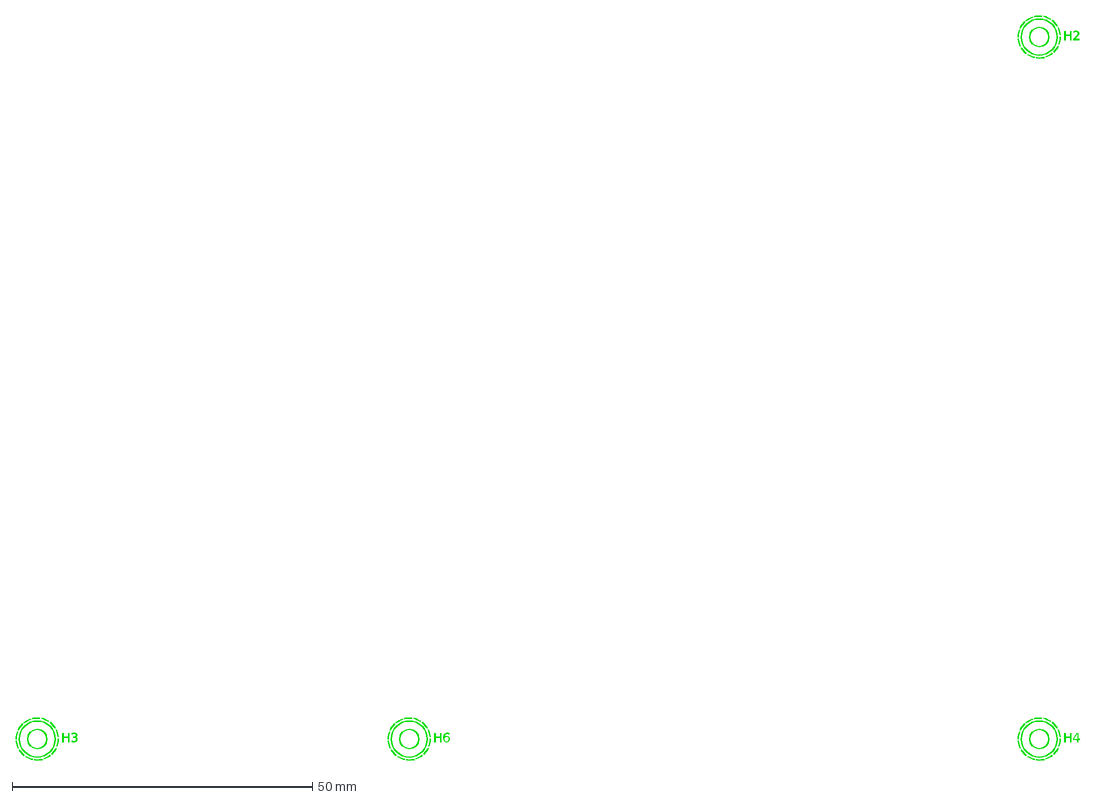
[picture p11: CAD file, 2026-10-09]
pcb/dxf/TriggerFlow_2_trous_GND.dxf
H2
H3
H4
H6

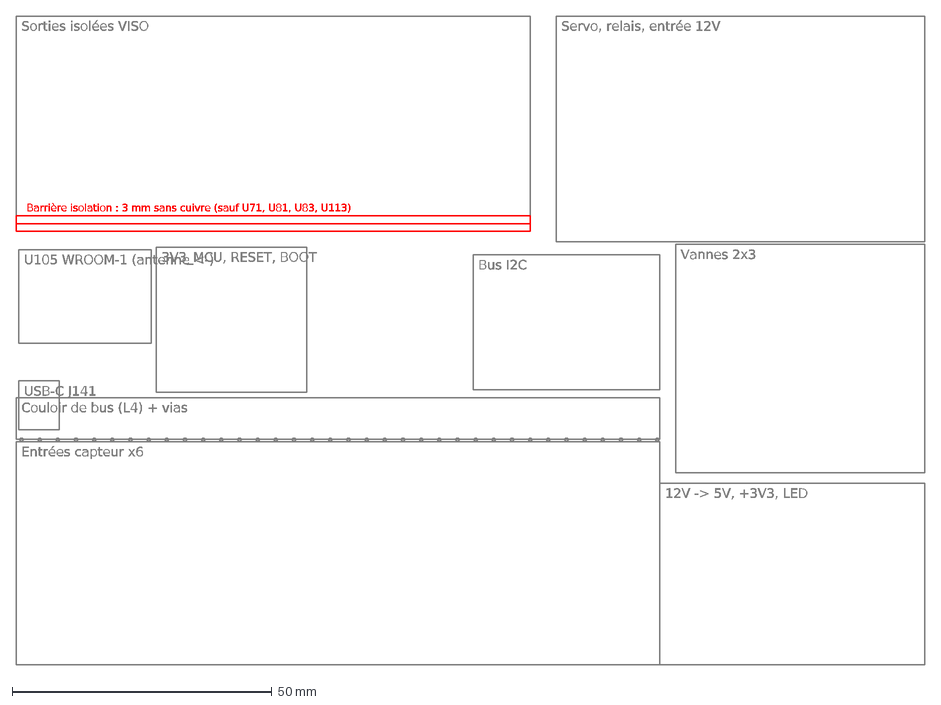
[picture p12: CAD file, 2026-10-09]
pcb/dxf/TriggerFlow_4_zones_document.dxf
Sorties isolées VISO
Servo, relais, entrée 12V
U105 WROOM-1 (antenne <-)
USB-C J141
3V3_MCU, RESET, BOOT
Bus I2C
Couloir de bus (L4) + vias
Vannes 2x3
Entrées capteur x6
12V -> 5V, +3V3, LED
Barrière isolation : 3 mm sans cuivre (sauf U71, U81, U83, U113)

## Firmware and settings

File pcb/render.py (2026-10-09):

from place import *
import re
import matplotlib; matplotlib.use("Agg")
import matplotlib.pyplot as plt
from matplotlib.patches import Rectangle, Circle, FancyBboxPatch
PLANES = {"GND", "+3V3", "+5V", "+12V", "VISO_3V3", "VISO_GND"}
PWRSET = {f"{p}9{i}" for p in ("CN","Q","D","F") for i in range(1,7)} | {f"R{i}" for i in range(93,105)}
# classement par fonction, numérotation EasyEDA du 10/10
ESP = {"U101","D101","D102","U104","U102","J101","SW101","SW102","R106","R105","R107","R108","C101","C102","C104","C105","C106","C103","U103",
       "CN111","U116","C116","C121"}
I2C = {"U111","U112","U113","U114","C111","C112","C113","C114","C115","R111","R112","R113","R114","R115"}
ISO = {"U117","U118","C124","C125","C126","R118","R119"}
PWR = {"J112","F112","Q112","R116","R117","D112","U115","L112","D113","C117","C118","C119","C120","C122","C137",
       "U131","L131","D131","C131","C132","C133","C134","C135","C136","R131","R132","R133","R134","R135","U132","C123","D133","J131",
       "RELAY131","Q131","R136","R137","D132","J132"}
def block(ref):
    if ref in PWRSET or ref in PWR: return "pwr"
    if ref in ESP: return "esp"
    if ref in I2C: return "i2c"
    if ref in ISO: return "iso"
    m = re.match(r"([A-Z]+)(\d+)", ref); p, d = m.group(1), int(m.group(2))
    if 70 <= d <= 92: return "iso"
    return "ana"
COL = {"ana": ("#E1F5EE", "#0F6E56"), "iso": ("#EEEDFE", "#534AB7"), "pwr": ("#FAECE7", "#993C1D"),
       "esp": ("#F1EFE8", "#5F5E5A"), "i2c": ("#F1EFE8", "#5F5E5A")}
def pinxy(p):
    r, n = p.split('.')
    x, y, rot = P[r]
    if r == "U101":                     # module WROOM-1 tourné : antenne à gauche
        n = int(n)
        if n <= 14: xn, yn = -9.0, -5.15 + (n - 1) * 1.27
        elif n <= 26: xn, yn = -7.0 + (n - 15) * 1.27, 12.75
        elif n <= 40: xn, yn = 9.0, 11.36 - (n - 27) * 1.27
        else: xn, yn = 0.0, 2.0
        return (x + yn, y - xn)
    return (x, y)
def mst(pts):
    if len(pts) < 2: return []
    used, rest, e = [pts[0]], pts[1:], []
    while rest:
        best = min(((a, b) for a in used for b in rest), key=lambda ab: math.dist(ab[0], ab[1]))
        e.append(best); used.append(best[1]); rest.remove(best[1])
    return e
def render(out, view=(0, BW, 0, BH), scale=1.0, labels=True, rats=True):
    w = (view[1]-view[0]); h = (view[3]-view[2])
    fig, ax = plt.subplots(figsize=(w/175*16*scale, h/175*16*scale))
    ax.set_xlim(view[0]-2, view[1]+2); ax.set_ylim(view[3]+2, view[2]-2); ax.set_aspect("equal"); ax.axis("off")
    ax.add_patch(FancyBboxPatch((0, 0), BW, BH, boxstyle="round,pad=0,rounding_size=2", fill=False, ec="#444", lw=1.2))
    zones = [((0,0,99,40),"#EEEDFE","Sorties isolées (VISO)"), ((104,0,175,43.5),"#FAECE7","Servo · relais · entrée 12 V"),
             ((127,44,175,88),"#FAECE7","Vannes 2 × 3"), ((124,90,175,125),"#FAECE7","12 V → 5 V · +3V3"),
             ((0,82,124,125),"#E1F5EE","Entrées capteur ×6"), ((88,46,124,72),"#F1EFE8","Bus I2C"), ((27,44.5,56,72.5),"#F1EFE8","3V3_MCU")]
    for (x1,y1,x2,y2),c,t in zones:
        ax.add_patch(Rectangle((x1,y1),x2-x1,y2-y1,fc=c,ec="none",alpha=0.55,zorder=0))
    ax.add_patch(Rectangle((0,73.5),124,8,fc="none",ec="#888",ls=(0,(3,2)),lw=0.8)); ax.plot([1,123],[81.6,81.6],color="#888",lw=0.6,ls=(0,(0.6,1.4)))
    ax.text(16,77.5,"couloir des bus THR / CS / ID / TLV_OUT (couche 4) · rangée de vias de couture côté analogique",fontsize=5*scale,color="#666",va="center",clip_on=True)
    x1,y1,x2,y2 = KEEPOUT_ANT; ax.add_patch(Rectangle((x1,y1),x2-x1,y2-y1,fc="none",ec="#E24B4A",ls=(0,(4,2)),lw=1))
    ax.text(3.5,69.6,"antenne",fontsize=4.5*scale,color="#A32D2D",ha="center",clip_on=True)
    ax.plot([0,99],[40,40],color="#A32D2D",lw=1.2,ls=(0,(5,3)))
    for hname,(hx,hy,kind) in HOLES.items():
        ax.add_patch(Circle((hx,hy),1.6,fc="white",ec="#333",lw=0.8,ls="--" if kind=="NPTH" else "-"))
        ax.add_patch(Circle((hx,hy),3.5,fc="none",ec="#999",lw=0.5,ls=":")); ax.text(hx,hy+5.2,hname,clip_on=True,fontsize=4.5*scale,ha="center",color="#333")
    for r,(x,y,rot) in P.items():
        q = rect(r); fc, ec = COL[block(r)]
        if r == "U101":
            ax.add_patch(Rectangle((q[0],q[1]),q[2]-q[0],q[3]-q[1],fc=fc,ec=ec,lw=0.9,zorder=4))
            ax.add_patch(Rectangle((q[0],q[1]),6.3,q[3]-q[1],fc="none",ec=ec,hatch="////",lw=0.5,zorder=4))
            for k in range(1, 41):
                px, py = pinxy(f"U101.{k}"); ax.add_patch(Circle((px, py), 0.35, fc=ec, ec="none", zorder=5))
            ax.text(x+3,y,"U101\nWROOM-1",fontsize=5.5*scale,ha="center",va="center",color=ec,clip_on=True); continue
        ax.add_patch(Rectangle((q[0],q[1]),q[2]-q[0],q[3]-q[1],fc=fc,ec=ec,lw=0.5,zorder=4))
        if labels:
            fs = 3.2*scale if (q[2]-q[0])*(q[3]-q[1]) < 12 else 4.5*scale
            ax.text(x,y,r,clip_on=True,fontsize=fs,ha="center",va="center",color=ec,zorder=5,rotation=90 if rot in (90,270) and (q[3]-q[1])>(q[2]-q[0]) and fs<4 else 0)
    if rats:
        for n,pins in nets.items():
            if n in PLANES: continue
            pts = list(dict.fromkeys(pinxy(p) for p in pins if p.split('.')[0] in P))
            for a,b in mst(pts): ax.plot([a[0],b[0]],[a[1],b[1]],color="#185FA5",lw=0.35,alpha=0.7,zorder=6)
    for (x1,y1,x2,y2),c,t in zones:
        if x2-x1>15: ax.text(x1+1,y1+1.8,t,clip_on=True,fontsize=6*scale,color="#444",weight="bold",va="top",zorder=7)
    fig.savefig(out,dpi=220,bbox_inches="tight",facecolor="white"); plt.close(fig)
if __name__ == "__main__":
    render("placement_complet.png")
    render("zoom_entree_voie1.png", view=(6,46,80,126), scale=2.6, rats=True)
    render("zoom_isole_alim.png", view=(0,100,0,48), scale=1.6)
    render("zoom_puissance.png", view=(100,175,0,125), scale=1.4)
    render("zoom_servo.png", view=(125,175,40,72), scale=2.4)
    tot = 0
    for n,pins in nets.items():
        if n in PLANES: continue
        pts=list(dict.fromkeys(pinxy(p) for p in pins if p.split('.')[0] in P))
        tot += sum(math.dist(a,b) for a,b in mst(pts))
    print("longueur ratsnest (signaux, hors plans) :", round(tot), "mm")

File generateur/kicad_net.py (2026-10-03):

#!/usr/bin/env python3
"""Lecture d'un .kicad_sch (v20260306) et calcul de la netlist par géométrie.
Sert à (1) extraire la spec du Bloc 1 existant, (2) vérifier le fichier généré."""
import sys, math, collections
import sexpdata
from sexpdata import Symbol


def S(x):
    return x.value() if isinstance(x, Symbol) else x


def find(node, name):
    return [c for c in node if isinstance(c, list) and c and S(c[0]) == name]


def first(node, name):
    r = find(node, name)
    return r[0] if r else None


def parse(path):
    with open(path, encoding="utf-8") as f:
        return sexpdata.loads(f.read())


def lib_pins(root):
    """{lib_id: [(num, name, x, y, angle)]} en coordonnées symbole (Y vers le haut)."""
    out = {}
    libs = first(root, "lib_symbols")
    for sym in find(libs, "symbol"):
        lid = sym[1]
        pins = []
        for sub in find(sym, "symbol"):
            for p in find(sub, "pin"):
                at = first(p, "at")
                num = first(p, "number")[1]
                nm = first(p, "name")[1]
                pins.append((str(num), nm, float(at[1]), float(at[2]), float(at[3])))
        out[lid] = pins
    return out


def pin_pos(px, py, at, mirror):
    x, y, rot = at
    a = math.radians(rot)
    rx = px * math.cos(a) - py * math.sin(a)
    ry = px * math.sin(a) + py * math.cos(a)
    if mirror == "x":
        ry = -ry
    elif mirror == "y":
        rx = -rx
    return (round(x + rx, 2), round(y - ry, 2))  # sch_y = placed_y - sym_y


class UF:
    def __init__(s): s.p = {}
    def f(s, a):
        s.p.setdefault(a, a)
        while s.p[a] != a:
            s.p[a] = s.p[s.p[a]]
            a = s.p[a]
        return a
    def u(s, a, b): s.p[s.f(a)] = s.f(b)


def on_seg(pt, a, b):
    (x, y), (x1, y1), (x2, y2) = pt, a, b
    if abs((x2 - x1) * (y - y1) - (y2 - y1) * (x - x1)) > 0.01:
        return False
    return min(x1, x2) - 0.01 <= x <= max(x1, x2) + 0.01 and min(y1, y2) - 0.01 <= y <= max(y1, y2) + 0.01


def analyse(path):
    root = parse(path)
    libs = lib_pins(root)
    uf = UF()
    comps, pinpts = [], []
    for s in find(root, "symbol"):
        lib = first(s, "lib_id")
        if not lib:
            continue
        lid = lib[1]
        at = first(s, "at")
        at = (float(at[1]), float(at[2]), float(at[3]))
        mir = first(s, "mirror")
        mir = S(mir[1]) if mir else None
        props = {p[1]: p[2] for p in find(s, "property")}
        ref, val = props.get("Reference"), props.get("Value")
        comps.append((ref, val, lid, at))
        for num, nm, px, py, _ in libs.get(lid, []):
            pinpts.append((ref, num, nm, lid, pin_pos(px, py, at, mir)))
    wires = []
    for w in find(root, "wire"):
        pts = first(w, "pts")
        a = tuple(round(float(v), 2) for v in first(pts, "xy")[1:3])
        b = tuple(round(float(v), 2) for v in find(pts, "xy")[1][1:3])
        wires.append((a, b))
        uf.u(a, b)
    juncs = [tuple(round(float(v), 2) for v in first(j, "at")[1:3]) for j in find(root, "junction")]
    # jonction ou extrémité posée sur un fil => connexion (T sans jonction = KiCad connecte l'extrémité seulement)
    endpoints = set(p for w in wires for p in w)
    for j in juncs:
        uf.f(j)
        for a, b in wires:
            if on_seg(j, a, b):
                uf.u(j, a)
    for (ref, num, nm, lid, p) in pinpts:
        uf.f(p)
        for a, b in wires:
            if on_seg(p, a, b):
                uf.u(p, a)
    labels = []
    for kind in ("label", "hierarchical_label", "global_label"):
        for l in find(root, kind):
            at = first(l, "at")
            p = (round(float(at[1]), 2), round(float(at[2]), 2))
            labels.append((kind, l[1], p))
            uf.f(p)
            for a, b in wires:
                if on_seg(p, a, b):
                    uf.u(p, a)
    nets = collections.defaultdict(lambda: {"pins": [], "names": set()})
    for (ref, num, nm, lid, p) in pinpts:
        nets[uf.f(p)]["pins"].append(f"{ref}.{num}")
    # noms : labels + power symbols
    for kind, name, p in labels:
        nets[uf.f(p)]["names"].add(name)
    for (ref, num, nm, lid, p) in pinpts:
        if lid.startswith("power:"):
            nets[uf.f(p)]["names"].add(lid.split(":")[1])
    # labels de même nom => même net
    byname = collections.defaultdict(list)
    for k, v in nets.items():
        for n in v["names"]:
            byname[n].append(k)
    merged = {}
    for n, ks in byname.items():
        for k in ks[1:]:
            uf.u(ks[0], k)
    final = collections.defaultdict(lambda: {"pins": set(), "names": set()})
    for k, v in nets.items():
        r = uf.f(k)
        final[r]["pins"] |= set(v["pins"])
        final[r]["names"] |= v["names"]
    return root, comps, pinpts, wires, juncs, labels, final


def report(path):
    root, comps, pinpts, wires, juncs, labels, nets = analyse(path)
    print(f"## {path}")
    print(f"composants={len([c for c in comps if not str(c[0]).startswith('#')])} fils={len(wires)} jonctions={len(juncs)} labels={len(labels)}")
    allpins = {f"{r}.{n}" for r, n, *_ in pinpts}
    connected = set()
    out = []
    for r, v in nets.items():
        pins = sorted(p for p in v["pins"] if not p.startswith("#PWR"))
        connected |= set(pins)
        names = "/".join(sorted(v["names"])) or "(sans nom)"
        if pins:
            out.append((names, pins))
    for names, pins in sorted(out):
        print(f"  NET {names:22s} {' '.join(pins)}")
    floating = sorted(p for p in allpins if not p.startswith("#PWR") and p not in connected)
    single = [(n, p) for n, p in out if len(p) < 2 and n == "(sans nom)"]
    print("  broches isolées:", floating)
    print("  nets à 1 broche sans nom:", single)
    return nets


if __name__ == "__main__":
    report(sys.argv[1])

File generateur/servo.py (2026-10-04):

"""Sortie servo : rail 6 V dédié (LM2596S-ADJ depuis +12V, coupable par le MCP23017) + buffer 5 V du signal."""
from kicadgen import *
SRC = "src_servo.kicad_sch"; FILE = "sortie_servo.kicad_sch"
def A(x, y): return (R2(x + DX), R2(y + DY))
def W(*pts): wire_abs(*[A(*p) for p in pts])
def G(x, y, rot=0): return add("power:GND", pwr_ref(), "GND", x, y, rot, hide_ref=True, hide_val=(rot != 0), val_at=(0, 3.81))
def PW(kind, x, y, rot=0):
    return add(f"power:{kind}", pwr_ref(), kind, x, y, rot, hide_ref=True, val_at=(0, -3.81) if rot == 0 else (0, 3.81))
def dv(lib, ref, val, x, y): return add(lib, ref, val, x, y, 270, ref_at=(2.54, -1.27), val_at=(2.54, 1.27), justify="left")
def cpol(ref, val, x, y): return add("Device:C_Polarized", ref, val, x, y, 0, ref_at=(2.54, -1.27), val_at=(2.54, 1.27), justify="left")

def layout():
    # ---- entrée +12V et découplage
    PW("+12V", 27.94, 76.2); W((27.94, 76.2), (88.9, 76.2))
    for ref, val, x in (("C129", "10uF", 35.56), ("C122", "10uF", 43.18), ("C123", "100nF", 50.8)):
        cap_v(ref, val, x, 80.01); G(x, 83.82)
    u = add("Regulator_Switching:LM2596S-ADJ", "U121", "LM2596S-ADJ", 101.6, 78.74, 0, ref_at=(0, -8.89), val_at=(0, -6.35))
    G(101.6, 88.9); W((101.6, 86.36), (101.6, 88.9))
    # ON/OFF
    W((88.9, 81.28), (76.2, 81.28)); lab("SERVO_OFF", 76.2, 81.28, 180)
    res_v("R123", "10k", 81.28, 87.63); W((81.28, 81.28), (81.28, 83.82))
    PW("+3V3", 81.28, 93.98, 180); W((81.28, 91.44), (81.28, 93.98))
    # commutation
    W((114.3, 81.28), (123.19, 81.28)); lab("SERVO_SW", 119.38, 83.82)
    add("Device:L", "L121", "33uH 4A", 127.0, 81.28, 90, ref_at=(0, -5.08), val_at=(0, -2.54))
    dv("Device:D_Schottky", "D121", "SS54", 119.38, 88.9); W((119.38, 85.09), (119.38, 81.28))
    G(119.38, 95.25); W((119.38, 92.71), (119.38, 95.25))
    # sortie V_SERVO
    W((130.81, 81.28), (193.04, 81.28)); lab("V_SERVO", 182.88, 81.28)
    add("Device:R", "R122", "3.9k", 146.05, 77.47, 0, ref_at=(-2.54, -1.27), val_at=(-2.54, 1.27), justify="right")
    W((114.3, 76.2), (116.84, 76.2), (116.84, 73.66), (146.05, 73.66)); lab("SERVO_FB", 121.92, 73.66)
    res_h("R121", "1k", 153.67, 73.66); W((146.05, 73.66), (149.86, 73.66)); W((157.48, 73.66), (160.02, 73.66)); G(160.02, 73.66, 90)
    for ref, val, x, pol in (("C124", "330uF", 157.48, True), ("C125", "100nF", 167.64, False), ("C126", "470uF", 177.8, True)):
        (cpol if pol else cap_v)(ref, val, x, 85.09); G(x, 91.44); W((x, 88.9), (x, 91.44))
    j = add("Connector_Generic:Conn_01x03", "J121", "SERVO", 198.12, 81.28, 0, ref_at=(0, -5.08), val_at=(0, 5.08))
    W((193.04, 78.74), (190.5, 78.74)); G(190.5, 78.74, 180)
    # ---- signal
    add("TriggerFlow:SN74AHCT1G125", "U122", "SN74AHCT1G125", 127.0, 111.76, 0, ref_at=(7.62, -6.35), val_at=(7.62, 6.35), justify="left")
    W((119.38, 109.22), (99.06, 109.22)); lab("SERVO_PWM", 99.06, 109.22, 180)
    res_v("R124", "10k", 106.68, 113.03); G(106.68, 119.38); W((106.68, 116.84), (106.68, 119.38))
    W((119.38, 114.3), (114.3, 114.3), (114.3, 119.38)); G(114.3, 119.38)
    G(127.0, 119.38)
    PW("+5V", 127.0, 101.6); W((127.0, 104.14), (127.0, 101.6)); W((127.0, 101.6), (130.81, 101.6))
    chh = cap_h("C127", "100nF", 134.62, 101.6); W((138.43, 101.6), (140.97, 101.6)); G(140.97, 101.6, 90)
    res_h("R125", "220", 138.43, 111.76)
    W((142.24, 111.76), (190.5, 111.76), (190.5, 83.82), (193.04, 83.82)); lab("SERVO_SIG", 165.1, 111.76)
    add("Device:D_TVS", "D122", "PESD5V0S1BB", 182.88, 115.57, 90, ref_at=(2.54, -1.27), val_at=(2.54, 1.27), justify="left")
    G(182.88, 119.38)
    zone("Rail V_SERVO 6 V (LM2596S-ADJ depuis +12V)", 20.32, 58.42, 205.74, 97.79)
    zone("Signal servo", 91.44, 99.06, 205.74, 127.0)
    note("Notes :\n"
         "• V_SERVO = 1,23 V × (1 + R122 / R121) = 1,23 × (1 + 3,9k / 1k) ≈ 6,0 V ; 3 A max (limitation interne du LM2596).\n"
         "• SERVO_OFF (MCP23017 GPB3) : haut ou haute impédance (R123 vers +3V3) = rail coupé ; bas = servo alimenté.\n"
         "• SERVO_PWM (GPIO13, LEDC 50 Hz) ; R124 maintient l'entrée basse au démarrage ; U122 sort un signal 5 V, R125 220 Ω série.\n"
         "• J121 : 1 = GND, 2 = V_SERVO, 3 = signal (brochage servo standard). D122 : TVS sur le signal.\n"
         "• C124 : électrolytique low-ESR, pas de polymère (stabilité du LM2596). C126 470 µF au plus près de J121.\n"
         "• PCB : boucle C129/C122-U121-D121 courte, cuivre et vias sous la languette de U121.",
         20.32, 134.62, 1.27)

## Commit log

2026-09-28 Revise component quantities in BOM-netlist
    Updated component counts in BOM for U3, Q1, R4, and R5.
2026-10-01 Fix output count for camera trigger in README
2026-10-03 Schéma validé (Blocs 1, 2, 3, 5, 5b, 8, 10, ESP32), Blocs 4 et 7 prêts, Bloc 6 remplacé par des prises Wi-Fi, module capteur universel, feuilles KiCad et générateur
    [alim_isolee.kicad_sch, alimentation.kicad_sch, module_capteur.kicad_sch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]
2026-10-04 Servo (rail 6 V) et relais ajoutés, moteur et PWM supprimés, Wi-Fi en point d'accès, implantation PCB v4 (175x125, 4 couches) et checklist de placement
    [placement_TriggerFlow.csv, sortie_relais.kicad_sch, sortie_servo.kicad_sch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]
2026-10-04 PCB : checklist et README alignés sur le placement réel (zones, couloir de bus, zone antenne, règles 4 couches, +5V en bandes, vias thermiques)
2026-10-05 Schéma complet validé (référence 05/10, ERC propre) : servo et relais avec repères EasyEDA, borniers KF128 3P, R123 3,9 kΩ ; placement PCB recalé sur la netlist de référence
    [placement_TriggerFlow.csv]
2026-10-09 PCB v1 : DXF pour EasyEDA (contour, trous, zones interdites, zones, plages Inner2), script EasyEDA des plans et zones, H7 supprimé
    [TriggerFlow_1_contour.dxf, TriggerFlow_2_trous_GND.dxf, TriggerFlow_3_zones_interdites.dxf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]
2026-10-09 v2 : module ESP32-S3-WROOM-1-N16R8 à la place de la DevKit (mêmes GPIO) ; 3V3_MCU dédié (U141), USB-C natif protégé (J141, U142), RESET / BOOT, console UART0 ; placement 305 composants, antenne au bo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
    [TriggerFlow_1_contour.dxf, TriggerFlow_2_trous_GND.dxf, TriggerFlow_3_zones_interdites.dxf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]
2026-10-09 v2 : GPIO réaffectés selon les côtés du module ; colonne de droite reprise de l'implantation EasyEDA (servo/relais/12 V à l'arrière, 5 V au coin avant droit) avec boucle LM2596 compacte ; I2C hors du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
    [TriggerFlow_1_contour.dxf, TriggerFlow_2_trous_GND.dxf, TriggerFlow_3_zones_interdites.dxf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]
2026-10-09 Checklist : boucle de découpage de U111 (L111 < 10 mm)
2026-10-09 v2 : feuille MCU générée (module ESP32-S3-WROOM-1, 3V3_MCU, USB-C, RESET/BOOT, console) en KiCad et variante EasyEDA ; netlist vérifiée contre netlist_v2_wroom.json
    [mcu_wroom.kicad_sch, src_mcu.kicad_sch]
2026-10-09 BOM-netlist v2 : DAC2_LDAC sur GPIO10
2026-10-09 Feuille MCU v2 : ajout des tirages I2C R108 / R109 (4,7 k vers +3V3), netlist revérifiée (37 nets, 0 écart)
    [mcu_wroom.kicad_sch, src_mcu.kicad_sch]
2026-10-09 v2 : numérotation EasyEDA du 10/10 (netlist EasyEDA = référence) ; correspondance vérifiée net par net ; placement, CSV, BOM-netlist, README, checklist et doc MCU renommés ; barrette console U85 à la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
    [placement_TriggerFlow.csv]
2026-10-09 pcb/README : nombre de composants
2026-10-09 v2 : 2e numérotation EasyEDA du 10/10 (export = référence) ; correspondance vérifiée net par net (0 écart) ; C87 supprimé ; CN111 en barrette 2 broches ; placement, CSV et documentation renommés
    [placement_TriggerFlow.csv]
2026-10-11 DXF v2 : textes à la numérotation EasyEDA actuelle (U101, J101, U117…), aperçu régénéré
2026-10-14 docs : bonnes pratiques PCB 4 couches (découplage, convertisseurs, couloir de bus, barrière, antenne, USB-C, placement, largeurs de pistes)
2026-10-14 docs : retrait du cuivre par rapport au bord (0,5 mm)
2026-10-15 Gerbers du 15/10 ; barrière d'isolation des DXF déplacée entre les rangées de pastilles des optos (Y 85,0–88,0) ; bonnes pratiques et README mis à jour
2026-10-15 Netlist EasyEDA du 15/10 (référence) : C122/C134 -> C138/C139, RELAY131 broches 1/2 inversées ; placement, README, BOM-netlist et checklist renommés ; P&P réel = netlist
2026-10-15 BOM : C138 et C139 en C335986 (ROQANG) — décision du 15/10
2026-10-15 DXF alignés sur la carte réelle : barrière Y 82,9-86,6, plages Inner2 lues dans le Gerber du 15/10 (19:08) ; Gerbers du 15/10 mis à jour ; docs
2026-10-15 pcb/README : Gerbers du dépôt = export de 19:08
